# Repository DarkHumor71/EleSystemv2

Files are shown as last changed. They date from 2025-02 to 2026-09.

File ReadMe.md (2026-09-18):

# EleSystemv2 - Smart Elevator & Building Management System



A comprehensive IoT-based elevator and building management system that integrates hardware control, electricity expense tracking, and a web-based admin dashboard. The system combines ESP32 microcontrollers for elevator control and QR code authentication with a full-stack web application for building and apartment management.

## 🏗️ Project Overview

EleSystemv2 is a multi-component system designed to modernize building management by:

- **Automated Elevator Control**: ESP32-based elevator controller with floor selection and queue management
- **QR Code Authentication**: Camera module for secure apartment access verification
- **Electricity Monitoring**: Track and calculate power consumption per apartment
- **Web Dashboard**: Modern React admin interface for managing buildings, apartments, and expenses
- **Role-Based Access**: Support for admin, moderator, and resident user roles

## 📁 Project Structure

```
EleSystemv2/
├── backend/              # Node.js/Express REST API
│   ├── config/          # Database and configuration files
│   ├── middleware/      # Authentication and authorization middleware
│   ├── models/          # MongoDB/Mongoose data models
│   └── routes/          # API route handlers
├── client/              # React admin dashboard
│   ├── public/          # Static assets
│   └── src/
│       ├── actions/     # Redux actions
│       ├── components/  # Reusable React components
│       ├── scenes/      # Page-level components
│       ├── reducers/    # Redux reducers
│       └── utils/       # Helper utilities
├── board/               # ESP32 elevator controller firmware
├── camera/              # ESP32-CAM QR code reader firmware
└── CAD/                 # KiCad PCB design files
```

## 🚀 Features

### Backend (REST API)

- **Authentication & Authorization**: JWT-based auth with role-based access control
- **Building Management**: CRUD operations for buildings with soft-delete support
- **Apartment Management**: Manage apartments within buildings, assign moderators
- **Expense Tracking**: Record and retrieve electricity usage data per apartment
- **Session Management**: Secure session handling for active users

### Frontend (React Dashboard)

- **Modern UI**: Material-UI components with light/dark mode
- **Data Visualization**: Charts and graphs for expense tracking
- **Building Administration**: Create and manage multiple buildings
- **Apartment Management**: Register apartments, generate QR codes
- **Expense Reports**: View and analyze electricity consumption
- **User Profiles**: Manage user information and roles

### Hardware Components

- **Elevator Controller** (`board/`):

  - 4-floor elevator control system
  - Button inputs and IR sensors per floor
  - Motor control (up/down)
  - 7-segment display for floor indication
  - Power monitoring and expense calculation
  - WiFi connectivity for data transmission

- **QR Code Reader** (`camera/`):
  - ESP32-CAM based authentication
  - Real-time QR code scanning
  - Server validation for apartment access
  - Scan cooldown to prevent duplicates

## 🛠️ Technology Stack

### Backend

- **Runtime**: Node.js
- **Framework**: Express.js
- **Database**: MongoDB with Mongoose ODM
- **Authentication**: JWT (jsonwebtoken)
- **Validation**: express-validator
- **Password Hashing**: bcryptjs

### Frontend

- **Framework**: React 18.3.1
- **State Management**: Redux Toolkit
- **UI Library**: Material-UI (MUI)
- **Routing**: React Router v7
- **Data Grid**: MUI X Data Grid
- **Charts**: Nivo, Chart.js
- **Form Handling**: Formik

### Hardware

- **Microcontroller**: ESP32 / ESP32-CAM
- **Connectivity**: WiFi (HTTP/HTTPS)
- **Development**: Arduino IDE
- **Libraries**: ESP32QRCodeReader, ArduinoJson, HTTPClient

### PCB Design

- **Tool**: KiCad
- **Modules**: Brain, Cabin, Display, Motor, Sensors

## 📋 Prerequisites

- **Node.js** v14+ and npm
- **MongoDB** v4+ (local or cloud instance)
- **Arduino IDE** with ESP32 board support
- **Git** for version control

## ⚙️ Installation & Setup

### 1. Clone the Repository

```bash
git clone https://github.com/DarkHumor71/EleSystemv2.git
cd EleSystemv2
```

### 2. Backend Setup

```bash
cd backend
npm install
```

Create a `config/default.json` file:

```json
{
  "mongoURI": "mongodb://localhost:27017/elesystem",
  "jwtSecret": "your_jwt_secret_key_here"
}
```

Or create a `.env` file with:

```
MONGO_URI=mongodb://localhost:27017/elesystem
JWT_SECRET=your_jwt_secret_key_here
PORT=5000
```

Start the backend server:

```bash
npm run server    # Development mode with nodemon
npm start         # Production mode
```

### 3. Frontend Setup

```bash
cd client
npm install
```

Update the proxy in `client/package.json` to match your backend URL:

```json
"proxy": "http://localhost:5000/"
```

Start the React development server:

```bash
npm start
```

### 4. Full Stack Development

From the `backend` directory:

```bash
npm run dev    # Runs both backend and frontend concurrently
```

### 5. Hardware Setup

#### Elevator Controller

1. Open `board/board.ino` in Arduino IDE
2. Update WiFi credentials:
   ```cpp
   const char* ssid = "your_wifi_ssid";
   const char* password = "your_wifi_password";
   ```
3. Update the server URL to match your backend IP
4. Upload to ESP32 board

#### Camera Module

1. Open `camera/camera.ino` in Arduino IDE
2. Update WiFi credentials and validation server URL
3. Upload to ESP32-CAM board

## 🔌 API Endpoints

### Authentication

- `POST /api/auth/login` - User login
- `POST /api/auth/apartment` - Apartment authentication

### Buildings

- `GET /api/building/:id` - Get building details
- `POST /api/building` - Create new building
- `PUT /api/building/:id` - Update building
- `DELETE /api/building/:id` - Soft delete building

### Apartments

- `GET /api/apartment/:id` - Get apartment details
- `POST /api/apartment` - Create new apartment
- `PUT /api/apartment/:id` - Update apartment
- `GET /api/apartment/exists` - Validate apartment (for QR authentication)

### Expenses

- `POST /api/expense` - Record electricity usage
- `GET /api/expense/apartment/:id` - Get expenses for apartment
- `GET /api/expense/building/:id` - Get all expenses for building
- `DELETE /api/expense/:id` - Delete expense record

## 🔐 Authentication & Authorization

The system uses JWT tokens with three permission levels:

1. **Admin**: Full system access, manage all buildings and apartments
2. **Moderator**: Building-specific access, manage apartments in their building
3. **Resident**: View personal apartment information and expenses

Middleware components:

- `auth.js` - Validates JWT token
- `admin.js` - Requires admin permissions
- `moderator.js` - Requires moderator permissions
- `building.js` - Validates building-level access
- `sameBuildingMod.js` - Ensures moderator belongs to the target building

## 📊 Data Models

### Building

- Name, email, address, city, state
- Soft delete support
- One-to-many relationship with apartments

### Apartment

- 4-digit PIN for authentication
- Apartment number (unique within building)
- Resident information (first name, last name, email)
- Moderator designation flag
- Reference to parent building

### Expense

- Time duration (in seconds)
- Power consumption (kWh)
- Cost calculation
- Timestamp of recording
- Reference to apartment

### Session

- Active user sessions
- Token management
- Automatic cleanup on server restart

## 🖥️ Dashboard Features

- **Admin Dashboard**: Overview of all buildings, apartments, and expenses
- **Moderator Dashboard**: Building-specific management
- **Apartment Dashboard**: Resident view of their expenses
- **Building List**: Browse and manage buildings
- **Apartment Management**: Add, edit, view apartments
- **Expense Tracking**: Visualize electricity usage over time
- **QR Code Generation**: Create QR codes for apartment authentication
- **Profile Management**: Update user information

## 🔧 Hardware Configuration

### Elevator Controller Pins

- **Buttons**: GPIO 19, 21, 22, 23 (floors 0-3)
- **IR Sensors**: GPIO 18, 5, 17, 16 (floors 0-3)
- **Motor Up**: GPIO 13
- **Motor Down**: GPIO 12
- **7-Segment Display**: Latch (26), Clock (25), Data (27)
- **Power Monitoring**: GPIO 34 (analog sensor)

### Camera Module

- ESP32-CAM with CAMERA_MODEL_AI_THINKER
- QR code scanning with 5-second cooldown
- HTTP validation with backend server

### FreeRTOS controller firmware

`board/board.ino` targets the ESP32 Arduino core, which includes FreeRTOS.
The elevator task runs every 10 ms at priority 4 and owns the buttons, floor
sensors, display, motor outputs, and emergency stop. A priority 1 network task
handles Wi-Fi, session verification, and expense uploads. An event group gates
motor operation on a verified session; a one-item FreeRTOS queue transfers an
expense report after the stop input is pressed. Upload failures are retried
without blocking motor shutdown. A full report queue latches a fault and
prevents another run.

The revised schematic uses an INA228 current monitor on I²C (SDA GPIO 16,
SCL GPIO 17). A third FreeRTOS task reads it and sends current samples through
a one-item queue; the motor task stays responsive if I²C is slow. Install the
`Adafruit INA228` Arduino library and its dependencies before building.
Set `SHUNT_RESISTANCE_OHMS` and `MAX_CURRENT_A` in `board/board.ino` to
match the assembled shunt and motor. The current values are provisional, so
expense measurements need calibration on hardware. The controller will not
enable its ready output until the INA228 initializes. The camera sketch
already uses a FreeRTOS QR scanning task.

## 🎨 Frontend Theming

The dashboard supports light and dark modes with customizable Material-UI themes. Theme configuration is in `client/src/theme.js`.

## 🧪 Testing

```bash
# Backend tests
cd backend
npm test

# Frontend tests
cd client
npm test
```

## 📦 Building for Production

### Frontend

```bash
cd client
npm run build
```

This creates an optimized production build in the `client/build` directory.

### Backend

The backend runs in production mode with:

```bash
cd backend
npm start
```

## 🤝 Contributing

Contributions are welcome! Please follow these steps:

1. Fork the repository
2. Create a feature branch (`git checkout -b feature/AmazingFeature`)
3. Commit your changes (`git commit -m 'Add some AmazingFeature'`)
4. Push to the branch (`git push origin feature/AmazingFeature`)
5. Open a Pull Request

## 📝 License

This project is licensed under the MIT License - see the [LICENSE](LICENSE) file for details.

## 👤 Author

**Mohammad Youssef** (DarkHumor71) **Ahmad Ayoub** (AhmadAybb) 

## 📞 Support

For questions, issues, or feature requests, please open an issue on the GitHub repository.

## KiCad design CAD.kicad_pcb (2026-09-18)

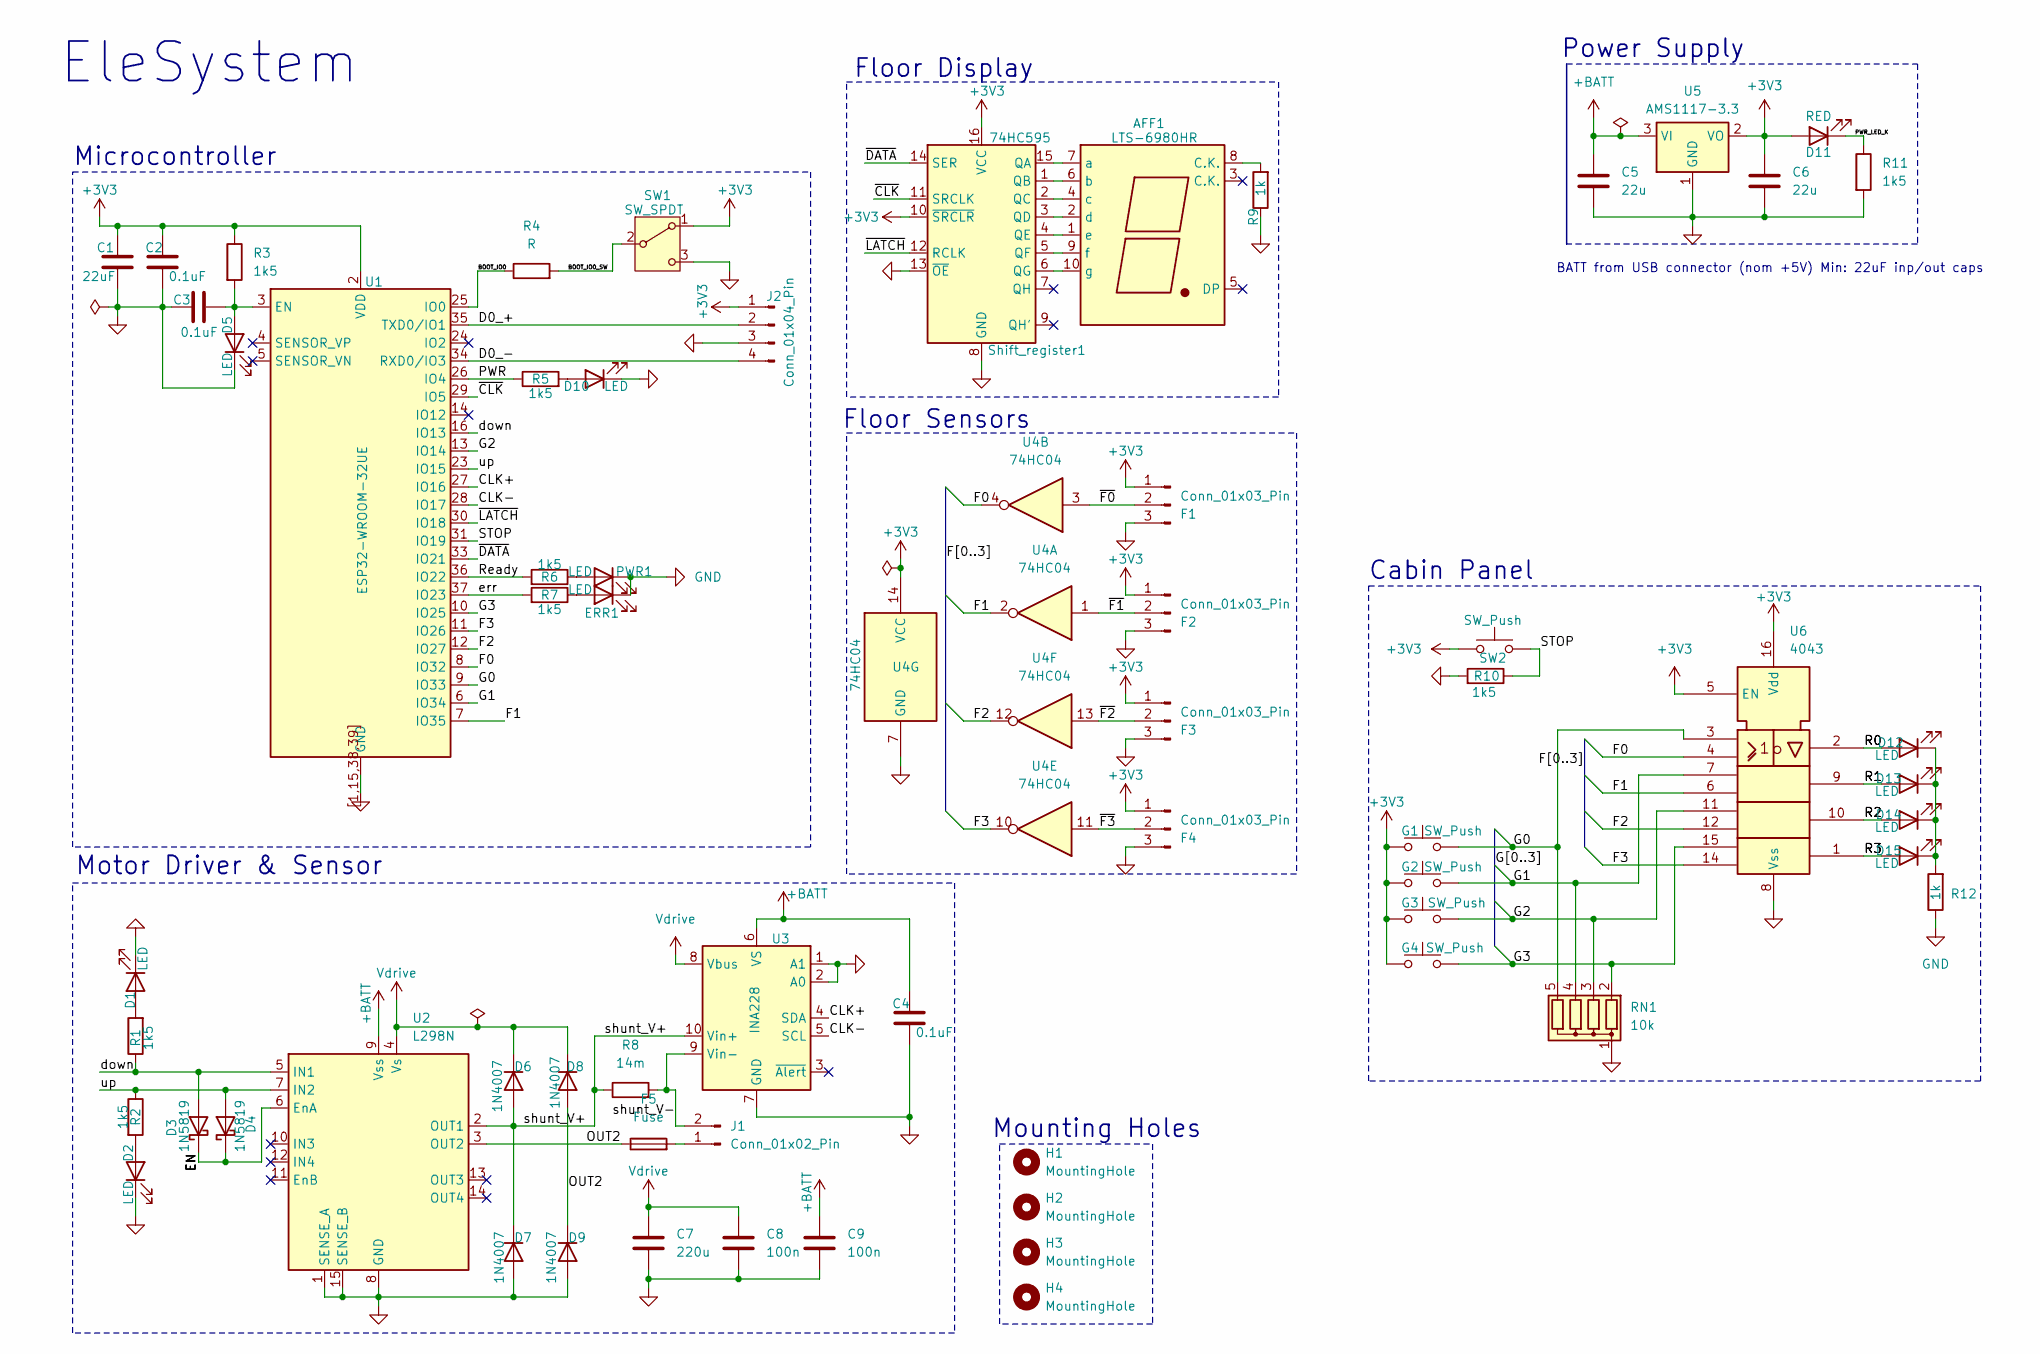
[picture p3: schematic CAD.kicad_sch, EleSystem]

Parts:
AFF1: LTS-6980HR; 7SegmentLED_LTS6760_LTS6780
C1: 22uF; C_0805_2012Metric
C2, C3, C4: 0.1uF; C_0402_1005Metric
C5, C6: 22u; C_0805_2012Metric
C7: 220u; C_Elec_8x10.2
C8, C9: 100n; C_0805_2012Metric
D1, D2, D5, D10: LED; LED_0603_1608Metric
D3, D4: 1N5819; D_1206_3216Metric
D6, D7, D8, D9: 1N4007; D_1206_3216Metric
D11: RED; LED_0603_1608Metric
D12, D13, D14, D15: LED; LED_1812_4532Metric_Pad1.30x3.40mm_HandSolder
ERR1: LED; LED_0603_1608Metric
F1, F2, F3, F4: Conn_01x03_Pin; PinHeader_1x03_P1.00mm_Vertical_SMD_Pin1Right
F5: Fuse; Fuse_0603_1608Metric
G1, G2, G3, G4: SW_Push; SW_PUSH_6mm_H7.3mm
H1, H2, H3, H4: MountingHole; MountingHole_2.2mm_M2
J1: Conn_01x02_Pin; PinHeader_1x02_P2.54mm_Vertical_SMD_Pin1Left
J2: Conn_01x04_Pin; PinHeader_1x04_P1.27mm_Vertical_SMD_Pin1Right
PWR1: LED; LED_0603_1608Metric
R1, R2, R3, R5, R6, R7, R10, R11: 1k5; R_0603_1608Metric
R4: R; R_0603_1608Metric
R8: 14m; R_2512_6332Metric
R9, R12: 1k; R_0603_1608Metric
RN1: 10k; R_Array_SIP5
SW1: SW_SPDT; SW_Slide_SPDT_Straight_CK_OS102011MS2Q
SW2: SW_Push; SW_Push_1P1T_NO_CK_KSC9xxG
Shift_register1: 74HC595; JEITA_SOIC-16_3.9x9.9mm_P1.27mm
U1: ESP32-WROOM-32UE
U2: L298N; TO-220-15_P2.54x5.08mm_StaggerOdd_Lead4.58mm_Vertical
U3: INA228; SMDIP-10_W7.62mm
U4: 74HC04; SSOP-16_4.4x5.2mm_P0.65mm
U5: AMS1117-3.3; SOT-223-3_TabPin2
U6: 4043; DIP-16_W7.62mm

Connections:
+3V3: C1.1, C2.1, C6.1, D11.2 (A), F1.1, F2.1, F3.1, F4.1, G1.1, G2.1, G3.1, G4.1, J2.1, R3.1, SW1.1 (A), SW2.2, Shift_register1.10 (~SRCLR), Shift_register1.16 (VCC), U1.2 (VDD), U4.14 (VCC), U5.2 (VO), U6.5 (EN), U6.16 (Vdd)
+BATT: C4.1, C5.1, C9.1, U2.9 (Vss), U3.6 (VS), U5.3 (VI); also elsewhere on the board
/BOOT_IO0: R4.1, U1.25 (IO0)
/BOOT_IO0_SW: R4.2, SW1.2 (B)
/CLK+: U1.27 (IO16), U3.4 (SDA)
/CLK-: U1.28 (IO17), U3.5 (SCL)
/D0_+: J2.2, U1.35 (TXD0/IO1)
/D0_-: J2.4, U1.34 (RXD0/IO3)
/EN: D3.1 (K), D4.1 (K), U2.6 (EnA)
/F0: U1.8 (IO32), U4.4, U6.4
/F1: U1.7 (IO35), U4.2, U6.6
/F2: U1.12 (IO27), U4.12, U6.12
/F3: U1.11 (IO26), U4.10, U6.14
/G0: G1.2, RN1.5 (R4), U1.9 (IO33), U6.3
/G1: G2.2, RN1.4 (R3), U1.6 (IO34), U6.7
/G2: G3.2, RN1.3 (R2), U1.13 (IO14), U6.11
/G3: G4.2, RN1.2 (R1), U1.10 (IO25), U6.15
/OUT2: D8.2 (A), D9.1 (K), F5.1, U2.3 (OUT2)
/PWR: R5.1, U1.26 (IO4)
/PWR_LED_K: D11.1 (K), R11.1
/R0: D12.2 (A), U6.2
/R1: D13.2 (A), U6.9
/R2: D14.2 (A), U6.10
/R3: D15.2 (A), U6.1
/Ready: R6.2, U1.36 (IO22)
/STOP: R10.1, SW2.1, U1.31 (IO19)
/down: D3.2 (A), R1.1, U1.16 (IO13), U2.5 (IN1)
/err: R7.2, U1.37 (IO23)
/shunt_V+: D6.2 (A), D7.1 (K), R8.1, U2.2 (OUT1), U3.10 (Vin+)
/shunt_V-: J1.2, R8.2, U3.9 (Vin-)
/up: D4.2 (A), R2.1, U1.23 (IO15), U2.7 (IN2)
/~CLK: Shift_register1.11 (SRCLK), U1.29 (IO5)
/~DATA: Shift_register1.14 (SER), U1.33 (IO21)
/~F0: F1.2, U4.3
/~F1: F2.2, U4.1
/~F2: F3.2, U4.13
/~F3: F4.2, U4.11
/~LATCH: Shift_register1.12 (RCLK), U1.30 (IO18)
GND: C1.2, C2.2, C3.1, C4.2, C5.2, C6.2, C7.2, C8.2, C9.2, D1.1 (K), D2.1 (K), D5.1 (K), D7.2 (A), D9.2 (A), D10.1 (K), ERR1.1 (K), F1.3, F2.3, F3.3, F4.3, J2.3, PWR1.1 (K), R9.1, R10.2, R11.2, R12.1, RN1.1 (common), SW1.3 (C), Shift_register1.8 (GND), Shift_register1.13 (~OE), U1.1 (GND), U1.15 (GND), U1.38 (GND), U1.39 (GND), U1.[1,15,38,39] (GND), U2.1 (SENSE_A), U2.8 (GND), U2.15 (SENSE_B), U3.1 (A1), U3.2 (A0), U3.7 (GND), U4.7 (GND), U5.1 (GND), U6.8 (Vss); also elsewhere on the board
unnamed: AFF1.8 (C.K.), R9.2
unnamed: AFF1.7 (a), Shift_register1.15 (QA)
unnamed: AFF1.6 (b), Shift_register1.1 (QB)
unnamed: AFF1.4 (c), Shift_register1.2 (QC)
unnamed: AFF1.2 (d), Shift_register1.3 (QD)
unnamed: AFF1.1 (e), Shift_register1.4 (QE)
unnamed: AFF1.9 (f), Shift_register1.5 (QF)
unnamed: AFF1.10 (g), Shift_register1.6 (QG)
unnamed: D1.2 (A), R1.2
unnamed: D2.2 (A), R2.2
unnamed: C3.2, D5.2 (A), R3.2, U1.3 (EN)
unnamed: D10.2 (A), R5.2
unnamed: D12.1 (K), D13.1 (K), D14.1 (K), D15.1 (K), R12.2
unnamed: ERR1.2 (A), R7.1
unnamed: F5.2, J1.1
unnamed: PWR1.2 (A), R6.1
Vdrive: C7.1, C8.1, D6.1 (K), D8.1 (K), U2.4 (Vs), U3.8 (Vbus)

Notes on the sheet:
Cabin Panel
Floor Display
Motor Driver & Sensor
BATT from USB connector (nom +5V) Min: 22uF inp/out caps
EleSystem
Microcontroller
Mounting Holes
Floor Sensors
Power Supply

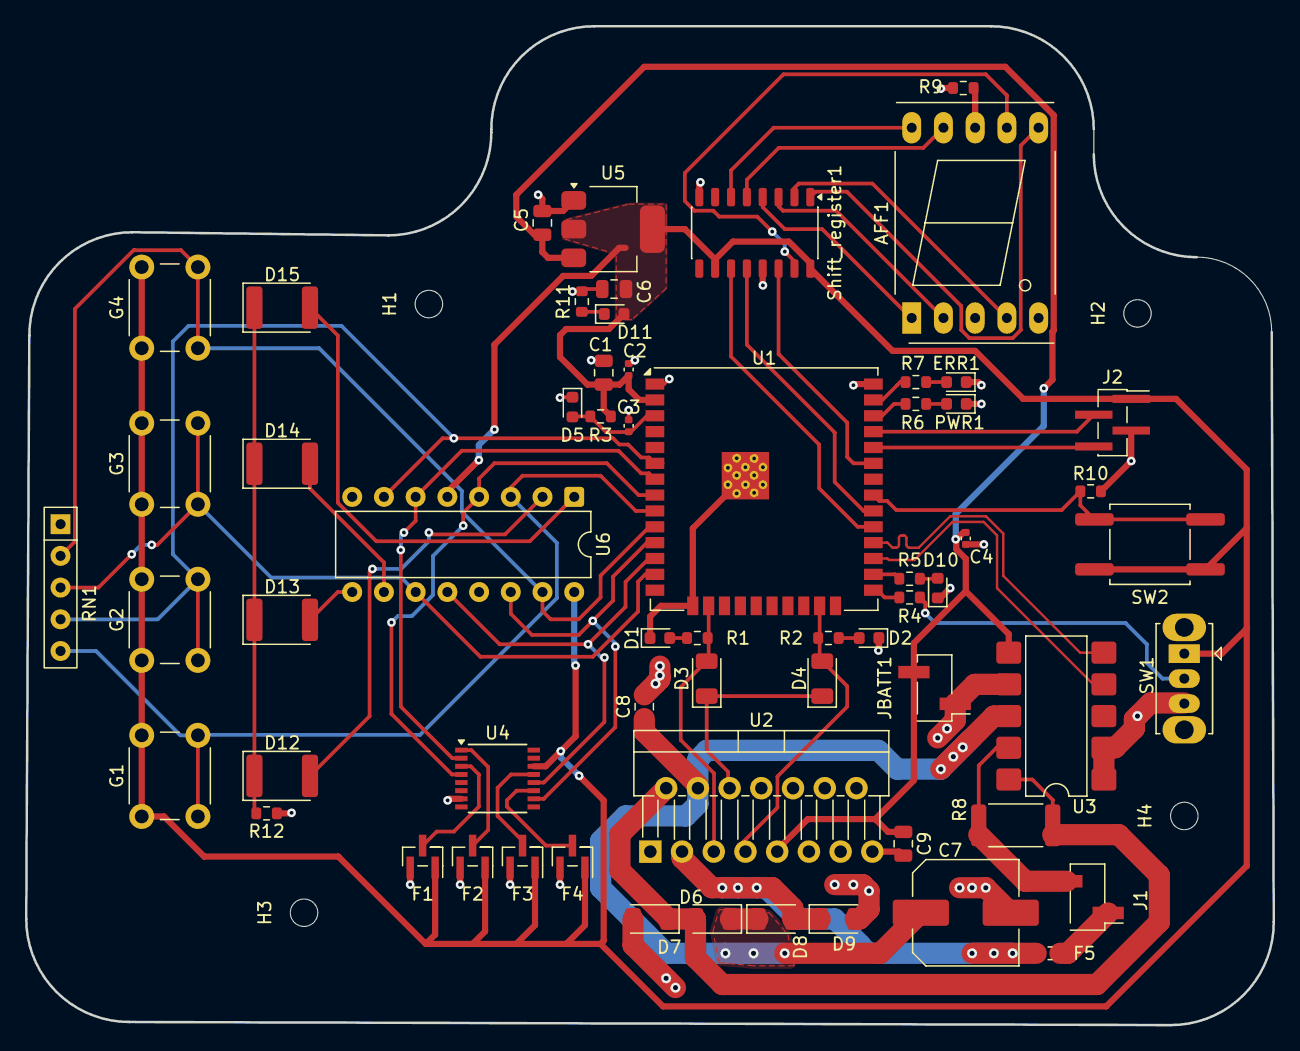
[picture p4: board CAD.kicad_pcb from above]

Board: 2 copper layers, 99.9 x 80.0 mm, 65 parts (0 on the bottom side), 56 nets.

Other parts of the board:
JBATT1: Conn_01x02_Pin; PinHeader_1x02_P2.54mm_Vertical_SMD_Pin1Left

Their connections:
+BATT: JBATT1.2; also elsewhere on the board
GND: JBATT1.1; also elsewhere on the board

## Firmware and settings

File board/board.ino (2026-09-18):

#include <WiFi.h>
#include <HTTPClient.h>
#include <Wire.h>
#include <Adafruit_INA228.h>
#include <freertos/FreeRTOS.h>
#include <freertos/event_groups.h>
#include <freertos/queue.h>
#include <freertos/task.h>

// The control task alone owns the motor, inputs, display, and elevator state.
// HTTP runs in a separate lower-priority task and cannot block the stop input.
const char *ssid = "hotcold1";
const char *password = "Mirna2016";
const char *MID = "ELE1";
const char *BRAIN_CODE = "P6p8h3uD&JQNWh";
const char *SESSION_URL = "http://192.168.1.103:5000/api/apartment/session";
const char *EXPENSE_URL = "http://192.168.1.103:5000/api/expense/create";

const int buttonPins[] = {33, 34, 14, 25};
const int irSensorPins[] = {32, 35, 27, 26};
const int elevatorMotorUpPin = 15;
const int elevatorMotorDownPin = 13;
const int PWR = 22;
const int ERR = 23;
const int STP = 19;
const int RDY = 4;
const int I2C[] = {16, 17};
const int latchPin = 18;
const int clockPin = 5;
const int dataPin = 21;
const uint8_t NUM[] = {0b00111111, 0b00000110, 0b01011011, 0b01001111};

const TickType_t CONTROL_PERIOD = pdMS_TO_TICKS(10);
const TickType_t NETWORK_RETRY = pdMS_TO_TICKS(1000);
const EventBits_t SESSION_READY = BIT0;
const EventBits_t STOP_ACTIVE = BIT1;
const EventBits_t SENSOR_READY = BIT2;
const int MAX_QUEUE_SIZE = 10;
// Set these to the actual shunt resistor and expected peak current on the PCB.
const float SHUNT_RESISTANCE_OHMS = 0.1f;
const float MAX_CURRENT_A = 3.2f;

struct ExpenseReport {
  float seconds;
  float power;
};

QueueHandle_t expenseQueue;
QueueHandle_t currentQueue;
EventGroupHandle_t sessionEvents;
Adafruit_INA228 currentSensor;

int floorQueue[MAX_QUEUE_SIZE];
int queueSize = 0;
int currentFloor = 0;
int targetFloor = 0;
int direction = -1;
bool moving = false;
bool stopLatched = false;
bool reportFault = false;
unsigned long motorStartTime = 0;
unsigned long arrivalTime = 0;
unsigned long lastButtonCheck = 0;
float motorElapsedTime = 0;
float currentSum = 0;
uint32_t sampleCount = 0;
float totalAvgCurrent = 0;

void setMotor(bool up, bool down) {
  digitalWrite(elevatorMotorUpPin, LOW);
  digitalWrite(elevatorMotorDownPin, LOW);
  if (up) digitalWrite(elevatorMotorUpPin, HIGH);
  if (down) digitalWrite(elevatorMotorDownPin, HIGH);
}

void updateDisplay() {
  digitalWrite(latchPin, LOW);
  shiftOut(dataPin, clockPin, MSBFIRST, NUM[currentFloor]);
  digitalWrite(latchPin, HIGH);
}

void addToQueue(int floor) {
  if (floor == currentFloor) return;
  for (int i = 0; i < queueSize; ++i)
    if (floorQueue[i] == floor) return;
  if (queueSize < MAX_QUEUE_SIZE) floorQueue[queueSize++] = floor;
}

void removeFromQueue(int floor) {
  for (int i = 0; i < queueSize; ++i) {
    if (floorQueue[i] != floor) continue;
    for (int j = i; j < queueSize - 1; ++j) floorQueue[j] = floorQueue[j + 1];
    --queueSize;
    return;
  }
}

int getNextFloor() {
  for (int pass = 0; pass < 2; ++pass) {
    for (int i = 0; i < queueSize; ++i)
      if ((direction == 1 && floorQueue[i] > currentFloor) ||
          (direction == -1 && floorQueue[i] < currentFloor)) return floorQueue[i];
    direction = -direction;
  }
  return floorQueue[0];
}

void finishMotorLeg(unsigned long now) {
  if (motorStartTime != 0) {
    motorElapsedTime += (now - motorStartTime) / 1000.0f;
    motorStartTime = 0;
  }
  if (sampleCount != 0) {
    // Preserve the project's existing current-to-power estimate.
    totalAvgCurrent += (currentSum / sampleCount) * 10.0f;
    currentSum = 0;
    sampleCount = 0;
  }
}

void handleStop(unsigned long now) {
  setMotor(false, false);
  digitalWrite(RDY, LOW);
  digitalWrite(ERR, HIGH);
  const bool hadSession = xEventGroupGetBits(sessionEvents) & SESSION_READY;
  xEventGroupSetBits(sessionEvents, STOP_ACTIVE);
  xEventGroupClearBits(sessionEvents, SESSION_READY);
  if (stopLatched) return;

  stopLatched = true;
  finishMotorLeg(now);
  moving = false;
  queueSize = 0;
  arrivalTime = 0;
  if (hadSession) {
    ExpenseReport report = {motorElapsedTime, totalAvgCurrent * 22.2f};
    // A full queue is a latched fault: do not silently discard an expense.
    if (xQueueSend(expenseQueue, &report, 0) != pdTRUE) reportFault = true;
  }
  motorElapsedTime = 0;
  totalAvgCurrent = 0;
  Serial.println("Emergency stop triggered");
}

void controlTask(void *) {
  TickType_t wake = xTaskGetTickCount();
  for (;;) {
    const unsigned long now = millis();
    if (digitalRead(STP) == HIGH) {
      handleStop(now);
      vTaskDelayUntil(&wake, CONTROL_PERIOD);
      continue;
    }
    stopLatched = false;
    xEventGroupClearBits(sessionEvents, STOP_ACTIVE);
    const bool authorized = !reportFault &&
      (xEventGroupGetBits(sessionEvents) & (SESSION_READY | SENSOR_READY)) ==
      (SESSION_READY | SENSOR_READY);
    digitalWrite(RDY, authorized ? HIGH : LOW);
    if (!authorized) {
      setMotor(false, false);
      if (moving) finishMotorLeg(now);
      moving = false;
      queueSize = 0;
      vTaskDelayUntil(&wake, CONTROL_PERIOD);
      continue;
    }
    digitalWrite(ERR, LOW);

    if (now - lastButtonCheck >= 200) {
      for (int i = 0; i < 4; ++i) {
        if (digitalRead(buttonPins[i]) == HIGH) {
          addToQueue(i);
          lastButtonCheck = now;
          break;
        }
      }
    }
    for (int i = 0; i < 4; ++i) {
      if (digitalRead(irSensorPins[i]) != HIGH) continue;
      if (moving && i == targetFloor) {
        setMotor(false, false);
        finishMotorLeg(now);
        moving = false;
        currentFloor = i;
        removeFromQueue(i);
        arrivalTime = now;
        updateDisplay();
      } else if (!moving && currentFloor != i) {
        currentFloor = i;
        updateDisplay();
      }
      break;
    }

    if (moving) {
      // Sensor I2C stays in another task, so a slow transaction cannot hold
      // the motor task away from STOP.
      float currentAmps;
      if (xQueueReceive(currentQueue, &currentAmps, 0) == pdTRUE) {
        currentSum += currentAmps;
        ++sampleCount;
      }
    } else if (queueSize > 0 && (arrivalTime == 0 || now - arrivalTime >= 2000)) {
      targetFloor = getNextFloor();
      if (targetFloor == currentFloor) {
        removeFromQueue(targetFloor);
      } else {
        moving = true;
        motorStartTime = now;
        setMotor(targetFloor > currentFloor, targetFloor < currentFloor);
      }
    }
    vTaskDelayUntil(&wake, CONTROL_PERIOD);
  }
}

void sensorTask(void *) {
  Wire.begin(I2C[0], I2C[1]);
  Wire.setTimeOut(20);
  for (;;) {
    if (!currentSensor.begin(INA228_I2CADDR_DEFAULT, &Wire)) {
      xEventGroupClearBits(sessionEvents, SENSOR_READY);
      Serial.println("INA228 not found");
      vTaskDelay(NETWORK_RETRY);
      continue;
    }
    currentSensor.setShunt(SHUNT_RESISTANCE_OHMS, MAX_CURRENT_A);
    xEventGroupSetBits(sessionEvents, SENSOR_READY);
    for (;;) {
      const float currentAmps = currentSensor.getCurrent_mA() / 1000.0f;
      xQueueOverwrite(currentQueue, &currentAmps);
      vTaskDelay(CONTROL_PERIOD);
    }
  }
}

bool postJson(const char *url, const String &payload) {
  HTTPClient http;
  http.setTimeout(2000);
  if (!http.begin(url)) return false;
  http.addHeader("Content-Type", "application/json");
  const int status = http.POST(payload);
  const bool success = status == 200 && http.getString() == "OK";
  http.end();
  return success;
}

void networkTask(void *) {
  ExpenseReport pending = {};
  bool havePending = false;
  for (;;) {
    // Expense creation consumes the current backend session.
    if (!havePending && xQueueReceive(expenseQueue, &pending, 0) == pdTRUE) {
      havePending = true;
      xEventGroupClearBits(sessionEvents, SESSION_READY);
    }
    if (WiFi.status() != WL_CONNECTED) {
      WiFi.reconnect();
      vTaskDelay(NETWORK_RETRY);
      continue;
    }
    if (havePending) {
      const String payload = String("{\"time\":") + String(pending.seconds, 3) +
        ",\"power\":" + String(pending.power, 2) +
        ",\"brain\":\"" + BRAIN_CODE + "\",\"mid\":\"" + MID + "\"}";
      if (postJson(EXPENSE_URL, payload)) {
        havePending = false;
        Serial.println("Expense submitted");
      } else {
        vTaskDelay(NETWORK_RETRY);
      }
      continue;
    }
    if (!(xEventGroupGetBits(sessionEvents) & SESSION_READY)) {
      const String payload = String("{\"brain\":\"") + BRAIN_CODE +
        "\",\"mid\":\"" + MID + "\"}";
      if (postJson(SESSION_URL, payload)) {
        // The stop may have arrived during the HTTP request.
        if (uxQueueMessagesWaiting(expenseQueue) == 0 &&
            !(xEventGroupGetBits(sessionEvents) & STOP_ACTIVE))
          xEventGroupSetBits(sessionEvents, SESSION_READY);
        else
          vTaskDelay(NETWORK_RETRY);
      } else {
        vTaskDelay(NETWORK_RETRY);
      }
    } else {
      vTaskDelay(pdMS_TO_TICKS(50));
    }
  }
}

void setup() {
  Serial.begin(115200);
  pinMode(PWR, OUTPUT);
  pinMode(ERR, OUTPUT);
  pinMode(RDY, OUTPUT);
  pinMode(elevatorMotorUpPin, OUTPUT);
  pinMode(elevatorMotorDownPin, OUTPUT);
  pinMode(STP, INPUT);
  pinMode(latchPin, OUTPUT);
  pinMode(clockPin, OUTPUT);
  pinMode(dataPin, OUTPUT);
  for (int i = 0; i < 4; ++i) {
    pinMode(buttonPins[i], INPUT);
    pinMode(irSensorPins[i], INPUT);
  }
  setMotor(false, false);
  digitalWrite(PWR, HIGH);
  digitalWrite(ERR, LOW);
  digitalWrite(RDY, LOW);
  updateDisplay();

  expenseQueue = xQueueCreate(1, sizeof(ExpenseReport));
  currentQueue = xQueueCreate(1, sizeof(float));
  sessionEvents = xEventGroupCreate();
  if (!expenseQueue || !currentQueue || !sessionEvents ||
      xTaskCreate(controlTask, "elevator", 4096, nullptr, 4, nullptr) != pdPASS) {
    Serial.println("Failed to start elevator task");
    digitalWrite(ERR, HIGH);
    return;
  }
  WiFi.mode(WIFI_STA);
  WiFi.begin(ssid, password);
  if (xTaskCreate(sensorTask, "ina228", 4096, nullptr, 2, nullptr) != pdPASS) {
    Serial.println("Failed to start sensor task");
    digitalWrite(ERR, HIGH);
  }
  if (xTaskCreate(networkTask, "network", 8192, nullptr, 1, nullptr) != pdPASS) {
    Serial.println("Failed to start network task");
    digitalWrite(ERR, HIGH);
  }
}

void loop() {
  vTaskDelay(pdMS_TO_TICKS(1000));
}

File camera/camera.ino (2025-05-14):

#include <WiFi.h>
#include <HTTPClient.h>
#include <ArduinoJson.h>
#include <ESP32QRCodeReader.h>

// Wi-Fi credentials
const char* ssid = "hotcold1";
const char* password = "Mirna2016";
const String MID ="ELE1";

// URLs
const char* validationServerUrl = "http://192.168.1.103:5000/api/apartment/exists";

// QR Reader setup
ESP32QRCodeReader reader(CAMERA_MODEL_AI_THINKER);
String lastID = "";

// === QR Task ===
void onQrCodeTask(void *pvParameters) {
  struct QRCodeData qrCodeData;
  unsigned long lastScanTime = 0;
  const unsigned long scanCooldown = 5000; // 5 seconds

  while (true) {
    if (reader.receiveQrCode(&qrCodeData, 100)) {
      Serial.println("Scanned new QRCode");

      if (qrCodeData.valid) {
        String payload = String((const char *)qrCodeData.payload);
        payload.trim();

        unsigned long currentTime = millis();

        if (payload == lastID && (currentTime - lastScanTime < scanCooldown)) {
          Serial.println("Duplicate scan ignored (within 5 seconds)");
        } else {
          lastID = payload;
          lastScanTime = currentTime;

          Serial.print("Valid QR payload: ");
          Serial.println(payload);
          sendIDToServer(payload);
        }
      } else {
        Serial.print("Invalid payload: ");
        Serial.println((const char *)qrCodeData.payload);
      }
    }

    vTaskDelay(100 / portTICK_PERIOD_MS);
  }
}


void setup() {
  Serial.begin(115200);

  // Connect to Wi-Fi
  WiFi.begin(ssid, password);
  Serial.print("Connecting to WiFi");
  while (WiFi.status() != WL_CONNECTED) {
    delay(500);
    Serial.print(".");
  }
  Serial.println("\nWiFi connected!");
  Serial.print("IP address: ");
  Serial.println(WiFi.localIP());

  // Setup QR reader
  reader.setup();
  reader.beginOnCore(1);
  Serial.println("QR Reader initialized on Core 1");

  // Start QR scanning task
  xTaskCreate(onQrCodeTask, "onQrCode", 4 * 1024, NULL, 4, NULL);
}

void loop() {
  delay(5000); // Idle loop
}

void sendIDToServer(String id) {
  if (WiFi.status() == WL_CONNECTED) {
    HTTPClient http;

    // Validate ID with main server
    http.begin(validationServerUrl);
    http.addHeader("Content-Type", "application/json");

    StaticJsonDocument<200> doc;
    doc["id"] = id;

    doc["mid"]= MID;

    String payload;
    serializeJson(doc, payload);
    Serial.println("Sending JSON to validation server: " + payload);

    int httpResponseCode = http.POST(payload);

    if (httpResponseCode == 200) {
      String response = http.getString();
      Serial.println("Validation Server Response: " + response);

      if (response == "OK") {
        Serial.println("Server acknowledged ID.");

      } else {
        Serial.println("Server did not respond with 'OK'.");
      }
    } else {
      Serial.print("Error sending POST to validation server: ");
      Serial.println(httpResponseCode);
    }

    http.end();
  } else {
    Serial.println("WiFi not connected.");
  }
}

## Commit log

2025-03-03 modified: client/package-lock.json renamed: client/src/App.js -> client/src/App.jsx new file: client/src/Layout/Alert.jsx modified: client/src/actions/auth.js modified: client/src/actions/types.js de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
2025-04-11 modified pin body
2025-04-14 deleted mock board
2025-04-22 modified: backend/config/default.json modified: backend/routes/API/apartment.js modified: backend/routes/API/expense.js modified: backend/server.js modified: client/package.json modified: client/src/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
2025-04-22 added expense route to account for current expense
2025-04-23 fixed download button
2025-05-15 modified: board/board.ino
2026-09-18 schem new implementation
    [Brain.kicad_sch, CAD.csv, CAD.kicad_pcb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]
2026-09-18 Implement FreeRTOS-based elevator control with INA228 current monitoring
    - Introduced FreeRTOS tasks for elevator control, sensor reading, and network communication.
    - Replaced blocking HTTP calls with non-blocking tasks to improve responsiveness.
    - Added INA228 current sensor support for real-time current monitoring.
    - Updated pin assignments and configurations for improved hardware compatibility.
    - Implemented event groups and queues for managing session states and expense reporting.
    - Enhanced error handling and emergency stop functionality.
    - Revised documentation to reflect new architecture and dependencies.
    [CAD.kicad_pcb, CAD.kicad_sch]

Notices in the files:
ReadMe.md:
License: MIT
